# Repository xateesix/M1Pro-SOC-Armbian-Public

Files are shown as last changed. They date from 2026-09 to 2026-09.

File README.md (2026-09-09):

# A3D M1 Pro X1  -  Armbian eMMC Firmware (RK3308BS)

Experimental from-source Armbian firmware for the Artillery M1 Pro S1-SOC control board (Rockchip **RK3308B-S**, board `rk3308bs-evb-m1soc`).

## Project intent

Turn an **otherwise barely usable or unusable** Artillery M1 Pro X1 into a **current mainline Klipper** printer by splitting roles across **new motion hardware** and the **factory S1-SOC board**.

| Role | Hardware | Target software |
|---|---|---|
| **Printer / motion (heavy lifting)** | New **host + CNC Mainboard with new toolhead board** (e.g. [BTT Manta M4P](https://www.biqu.equipment/products/bigtreetech-manta-m4p) + [FYSETC H36](https://www.fysetc.com/products/fysetc-h36-mainboard)) | Mainline **Klipper** on the MCU stack  -  motion, heaters, fans, probe |
| **Display + camera node** | Factory **RK3308 S1-SOC** (this firmware) | **KlipperScreen** on the stock LCD, **Crowsnest** for webcam streaming |

The S1-SOC is **not** the printer MCU. It is an **external companion**  -  UI and camera  -  while the new host + toolhead boards run Klipper for the machine.

The companion image is functional: the **480x272 display works** (Linux DRM/VOP + framebuffer console), **WiFi** is managed by NetworkManager, thermal/touch are working, and the **KlipperScreen + Crowsnest** companion stack is staged for install via KIAUH. Remaining work is on the **motion stack** (Z-stop/probe) and finishing KlipperScreen/Crowsnest configuration.

> ## WARNING  -  READ FIRST
>
> - **Experimental**  -  not supported by Artillery 3D; no warranty.
> - **Void warranty**  -  flashing and hardware mods void manufacturer warranty.
> - **Dangerous voltages**  -  mains AC and 24 V DC. Fire and shock risk.
> - **Extra hardware**  -  USB-C **data** cable, USB-TTL serial adapter (FT232RL), Windows PC with RKDevTool, MASKROM recovery access, plus the **host + toolhead upgrade** for printer control.
> - **You assume all risk**  -  authors are not liable for damage or injury.
>
> Full text: [`docs/WARNING.md`](docs/WARNING.md)

> **Hardware upgrade required for printing:** Motion and Klipper MCU duties need a **3/4-axis host** and **toolhead board** (see below). This S1-SOC image is for the **companion display/camera node**. Repinning JST connectors and high-voltage work can **destroy hardware** or **cause fire**. See [`docs/UPGRADE_PATH.md`](docs/UPGRADE_PATH.md).

## Target architecture (read before flash)

### Motion stack (required for Klipper printing)

| Part | Example |
|---|---|
| **Host** (3 or 4 axis + Klipper MCU) | [BIGTREETECH Manta M4P](https://www.biqu.equipment/products/bigtreetech-manta-m4p) |
| **Toolhead / CNC board** | [FYSETC H36](https://www.fysetc.com/products/fysetc-h36-mainboard) |

This combo does the **heavy lifting**  -  steppers, hotend, bed, probe, and mainline Klipper firmware on the MCU.

**Work in progress:** **Z-stop / Z-probe** still required. Current direction: **Sovol Eddy** in a **custom housing** on the front print head cover. The H36 is chosen for high-temp rating, **3-wire PWM** fan headers, enough GPIO for current and future hardware, and [hopefully] **sideways fit** inside the print head cover.

Details: [`docs/UPGRADE_PATH.md`](docs/UPGRADE_PATH.md).

### 3D printed parts (required for rebuild)

| Part | STEP model |
|---|---|
| Manta M4P mounting bracket | [`models/M4P_M1Pro_Mounting_bracket.step`](models/M4P_M1Pro_Mounting_bracket.step) |
| Power supply relocate bracket | [`models/M1-PowerSupply-Relocate.step`](models/M1-PowerSupply-Relocate.step) |

Print from the STEP files or export STL in your CAD tool. Details: [`docs/UPGRADE_PATH.md`](docs/UPGRADE_PATH.md).

### S1-SOC companion (this repository)

Flash this repo's image on the **factory S1-SOC** to drive:

- **KlipperScreen** on the built-in **480x272** display
- **Crowsnest** for USB webcam streaming to your Klipper stack

The companion talks to your **real Klipper host** (Moonraker on the Manta side) over the network. It does **not** replace the motion boards.

Configuration guide (KlipperScreen  ->  Moonraker IP, Crowsnest on companion, Mainsail/Fluidd webcam URL): [`docs/COMPANION_SETUP.md`](docs/COMPANION_SETUP.md).

Skilled **JST repinning**, **mains / 24 V** awareness, and acceptance of serious risk are required. See [`docs/WARNING.md`](docs/WARNING.md).

## What this is

Experimental **Armbian eMMC firmware** for the **RK3308BS S1-SOC** on the Artillery M1 Pro X1. It replaces the factory Linux image with a lean OS intended as a **KlipperScreen + Crowsnest companion node**, using the stock display and WiFi.

This repository provides the **companion-board firmware and build pipeline**, not the main Klipper MCU firmware for the Manta/H36 stack.

## Media (in this repository)

| Asset | File |
|---|---|
| Hardware overview video (~45 MB) | [`Media/VID_20260615_141308204.mp4`](Media/VID_20260615_141308204.mp4) |
| Boot logo source (BMP) | [`Media/boot-logo-artillery.bmp`](Media/boot-logo-artillery.bmp) |

The custom boot logo is compiled into boot assembly by `tools/build-armbian-bootimg.sh`.

Board overview and control-header pin identification (case light bar, RGB JST, +LED-).
## USB-C data cable (required for flash)

MASKROM flashing and RKDevTool need a **data-capable** USB connection from your PC to the control board USB port.

| Need | Detail |
|---|---|
| **Cable** | Good-quality **USB-C data cable** (USB-C to USB-A or USB-C, matching your PC) |
| **Not sufficient** | Charge-only cables, many cheap phone cables, or long/under-spec cables |
| **Symptom if wrong** | RKDevTool never sees the device, or download fails mid-flash |

Use a cable rated for **data + power**. Short, branded or known data cables are more reliable than generic charge cords. If flash is unstable, try another cable and USB port before changing firmware.

## RKDevTool (required on Windows)

Rockchip firmware flash and the final eMMC **pack** step both use **RKDevTool** on a **Windows PC**. This repository does not bundle RKDevTool.

| Need | Detail |
|---|---|
| **Tool** | RKDevTool (v2.86 or newer recommended)  -  includes `RKDevTool.exe` for flashing and `bin/AFPTool.exe` + `bin/RKImageMaker.exe` for packing |
| **Driver** | Rockchip USB driver via **DriverAssistant** (install before first flash) |
| **Use** | **Upgrade Firmware** tab with a monolithic `.img` (not balenaEtcher / raw `dd`) |
| **USB cable** | Good-quality **USB-C data cable** (see section above) |
| **Recovery** | Board in **MASKROM** (recovery button / maskrom pads + USB) |

**Download and documentation:**

- **Firefly** (ROC-RK3308-CC / RK3308): [Resource downloads (RKDevTool)](https://en.t-firefly.com/doc/download/53.html)  -  [Burning firmware guide](https://wiki.t-firefly.com/en/ROC-RK3308-CC/burning_firmware.html)
- **Radxa** (Rockchip tools): [RKDevTool documentation](https://docs.radxa.com/en/zero/zero3/low-level-dev/rkdevtool)  -  [Windows tools download](https://dl.radxa.com/tools/windows/) (`RKDevTool_Release_v2.86.zip`, `DriverAssistant`)

After installing, run `RKDevTool.exe` as Administrator. Flash steps: [`FLASH_RKDEVTOOL.md`](FLASH_RKDEVTOOL.md).

## USB serial adapter (recommended)

A **USB to TTL serial adapter** lets you see boot logs and log in when WiFi or the display are not set up.

| Need | Detail |
|---|---|
| **Adapter** | FTDI **FT232RL** USB-TTL (3.3 V logic)  -  e.g. [DSD TECH SH-U09C](https://www.amazon.com/DSD-TECH-Adapter-FT232RL-Compatible/dp/B07BBPX8B8) |
| **Level** | Set adapter jumper to **3.3V** (RK3308 UART is 3.3 V TTL) |
| **Wiring** | GND  ->  GND, adapter TXD  ->  board RX, adapter RXD  ->  board TX (UART3 header) |
| **Baud** | **1500000** |
| **Console** | **`ttyS3`** at 1500000 baud (older factory notes mention `ttyFIQ0`) |

Use PuTTY, Tera Term, or `picocom` at **1500000 8N1**. FTDI VCP drivers: [ftdichip.com](https://ftdichip.com/drivers/vcp-drivers/).

Full wiring and terminal notes: [`docs/SERIAL_CONSOLE.md`](docs/SERIAL_CONSOLE.md).

## Download and flash (companion image)

Host-role rule: if build and flash are on different machines, upload the image to the flashing machine first and run flash there. Do not run `upgrade_tool` or `rkdeveloptool` on the build machine.

1. Obtain the monolithic eMMC image `rk3308bs-1.0.0-<release-tag>-emmc.img` (from **GitHub Releases** or your own from-source build).
2. Flash with RKDevTool  ->  **Upgrade Firmware** (or `upgrade_tool uf <image>` on Linux)
3. **Change the default password** on first login

| Account | Username | Default password |
|---|---|---|
| Normal user | `m1prox1` | `m1prox1` |
| Root | `root` | `m1prox1` |

WiFi credentials can be pre-baked at build time (private builds) or configured on first boot with `nmcli` / `nmtui` (NetworkManager).

Release assets: [`docs/RELEASE.md`](docs/RELEASE.md)

## Build from source (GPL / customization)

The firmware is compiled **from source** with Armbian: the board's kernel (with the RK3308BS patch set), rootfs, and the flashable Rockchip eMMC image are all produced by the scripts in this repository.

### Build requirements

| Component | Notes |
|---|---|
| **Linux** (Ubuntu/Debian) | Armbian from-source build + Rockchip packaging (Linux-only tooling) |
| **RKDevTool** or `upgrade_tool` | Flash the resulting image to eMMC |
| **Serial** | USB-TTL adapter (FT232RL, 3.3 V)  -  see section above |

### Steps

```bash
git clone <this-repository-url>
cd <repository-directory>

# Install host build dependencies (first time)
bash tools/install-build-deps.sh

# Build kernel + rootfs from source and pack the flashable eMMC image.
# RELEASE_TAG is mandatory and names the release/output image.
RELEASE_TAG=my-build bash tools/build-from-source-linux.sh
```

Output: `releases/<RELEASE_TAG>/rk3308bs-1.0.0-<RELEASE_TAG>-emmc.img`

To capture a kernel DRM/boot trace for debugging, set `DRM_DEBUG=1` (adds `drm.debug` to the kernel cmdline); production images build with `DRM_DEBUG=0`.

### What the scripts do

| Script | Role |
|---|---|
| `tools/install-build-deps.sh` | Host packages and tools |
| `tools/fetch-build-sources.sh` | Fetch/verify build inputs (factory templates) |
| `tools/build-from-source-linux.sh` | Canonical build entrypoint (kernel+rootfs+pack) |

## Configuration

| File | Purpose |
|---|---|
| `config.env.example` | Defaults  -  safe to commit |
| `config.env.public.example` | Public-facing example values |
| `config.env` | **Local only**  -  never commit (holds real credentials/URLs) |

## Feature status

| Feature | Status |
|---|---|
| S1-SOC companion image (from-source Armbian, kernel 6.18.x) | Working |
| 480x272 parallel-RGB display + framebuffer console + boot logo | Working |
| Serial `ttyS3` @ 1500000 | Working |
| Thermal / TSADC (RK3308BS linear conversion) | Working |
| Goodix touch (GT911, I2C3) | Working |
| WiFi (RTL8189FS) via **NetworkManager** | Working |
| **KlipperScreen** (companion role) | Staged via KIAUH  -  install on device |
| **Crowsnest** (companion role) | Staged via KIAUH  -  install on device |
| Main Klipper MCU (Manta M4P + H36) | **Required separate upgrade**  -  not this image |
| Z-stop / bed probe (motion stack) | **WIP**  -  Sovol Eddy + custom cover mount |
| Case light bar (+LED-) | Pin identified; driver in progress |
| RGB pebbles (WS2812) | Not supported |
| Factory Makerbase UI | Not included |

GPIO map: [`docs/GPIO_AND_HARDWARE.md`](docs/GPIO_AND_HARDWARE.md)
Boot logo: [`docs/BOOT_LOGO.md`](docs/BOOT_LOGO.md)

The image build stages KIAUH, Klipper, Moonraker, KlipperScreen, and Crowsnest source trees under `/opt` during rootfs customization; run `/usr/local/sbin/rk3308bs-setup-companion-stack.sh` on device to install KlipperScreen/Crowsnest via KIAUH.

## Build pipeline

```text
tools/install-build-deps.sh   ->  host build dependencies

RELEASE_TAG=<tag> bash tools/build-from-source-linux.sh
  |-- Armbian compile.sh          (kernel + rootfs from source, patches/ applied)
  |-- build-emmc-release.sh       (stage pack_input from the compiled image)
  |    |-- build-armbian-bootimg.sh  (boot.img: kernel + custom DTB + resource/logo)
  |-- tools/pack-firmware-linux.sh   (afptool/rkImageMaker -> monolithic RKFW image)
```

Output: `releases/<tag>/rk3308bs-1.0.0-<tag>-emmc.img`

## Repository layout

| Path | Description |
|---|---|
| `tools/build-from-source-linux.sh` | Canonical build entrypoint |
| `tools/` | From-source build + Rockchip packaging scripts |
| `patches/` | Kernel and DTS patches (GPL) |
| `config/` | Kernel config fragments |
| `userpatches-chroot/`, `userpatches-kernel/`, `userpatches-boot/` | Armbian build hooks |
| `overlay/` | On-device services + helpers baked into the rootfs |
| `models/` | 3D printed bracket STEP files |
| `docs/` | User documentation |
| `releases/` | Build output (git-ignored) |

## License and disclaimer

GPL-licensed components remain under their respective licenses. Provided as-is for research and self-hosting. Not affiliated with Artillery 3D.

## Changelog

See [`CHANGELOG.md`](CHANGELOG.md).

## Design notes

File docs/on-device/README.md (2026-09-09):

# On-device documentation

Companion firmware for the Artillery M1 Pro X1 S1-SOC (RK3308BS). Additional guides are in this folder.

## Login credentials

Change passwords after first boot.

| Account | Username | Password |
|---|---|---|
| Normal user | `m1prox1` | `m1prox1` |
| Root | `root` | `m1prox1` |

WiFi is **not** pre-configured on the published image.

## Repository media

| Asset | Path on SD/eMMC |
|---|---|
| Hardware overview video | Not on device — see repo [`Media/VID_20260615_141308204.mp4`](https://github.com/xateesix/M1-SOC-Armbian-Build-scripts-public/blob/main/Media/VID_20260615_141308204.mp4) |

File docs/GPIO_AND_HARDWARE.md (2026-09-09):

# GPIO map

Confirmed: case light bar = GPIO2_B3 (gpiochip2 line 11, gpio75), 24 V enable.
RGB NeoPixel: not supported.
Serial console: ttyS3 @ 1500000  -  see docs/SERIAL_CONSOLE.md.

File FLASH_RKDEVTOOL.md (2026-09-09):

# RK3308BS  -  RKDevTool flash guide (Artillery M1 Pro S1-SOC)

## Host role rule (mandatory)

- Build host and flash host are different roles.
- Never run `upgrade_tool` or `rkdeveloptool` on the build host.
- Always upload firmware image from build host to flash host first, then flash on flash host.

Linux flash-host example (SSH alias `flashpc`):

```bash
IMG="rk3308bs-1.0.0-v64-from-source-linux-emmc.img"
SRC="/home/YOUR_USERNAME/scratch/Projects/rk3308bs-workspace/M1-SOC-Armbian-Build/releases/v64-from-source-linux/$IMG"

rsync --partial --append-verify "$SRC" flashpc:~/rk3308bs-firmware/
ssh flashpc "sha256sum ~/rk3308bs-firmware/$IMG"
ssh flashpc "sudo upgrade_tool uf ~/rk3308bs-firmware/$IMG"
```

## Install RKDevTool (not included in this repo)

Use a **Windows PC**. Download RKDevTool and the Rockchip USB driver from vendor tool pages:

| Source | Links |
|-----|----|
| **Firefly** | [RKDevTool download](https://en.t-firefly.com/doc/download/53.html)  -  [ROC-RK3308-CC burning guide](https://wiki.t-firefly.com/en/ROC-RK3308-CC/burning_firmware.html) |
| **Radxa** | [RKDevTool docs](https://docs.radxa.com/en/zero/zero3/low-level-dev/rkdevtool)  -  [Windows tools](https://dl.radxa.com/tools/windows/) |

Recommended: `RKDevTool_Release_v2.86.zip` plus **DriverAssistant**. Install the driver first, then run `RKDevTool.exe` as Administrator.

## USB cable

Use a **good-quality USB-C data cable** between the PC and the board USB port. Charge-only or poor cables often prevent MASKROM detection or cause failed downloads. Try a short, known data cable and a direct motherboard USB port if RKDevTool does not see the device.

## Use Upgrade Firmware + monolithic `.img`

1. Enter **MASKROM** (recovery button / maskrom pads + USB).
2. Open **RKDevTool**.
3. Tab: **Upgrade Firmware** (second tab).
4. **Firmware:** browse to a single monolithic `.img` file.
   - Do **not** load a custom `config.cfg` with separate partition files.
   - Do **not** use **Advanced  ->  Write by address**.
5. Click **Upgrade** / **Run**.
6. Watch the log  -  you **must** see:
   - `Download Boot Success`
   - `Download IDB Success`
   - `Download Firmware Start` with **`Gpt=1`**
   - `Start to download rootfs, offset=0x...` (multi-minute write for large images)
   - `Download Firmware Success` (ret=0, not `ret=1`)
7. Unplug USB, power cycle.

If **Download Boot** fails to start:

- **Advanced**  ->  **Download Loader**  ->  use `MiniLoaderAll.bin` from your partition templates or factory extract
- Immediately repeat step 5 on **Upgrade Firmware** with the **full** `.img`.

---

## Factory reference image

Known-good monolithic package (use for recovery and as packaging reference):

```
KLP_IMG_ARTILLERY_M1_PRO_S1-SOC_20251126_Beta (1)/KLP_IMG_ARTILLERY_M1_PRO_S1-SOC_20251126_Beta.img
```

Unpacked structure matches our repacks:

| Component | Factory | Our repacks |
|---|---|---|
| `boot.bin` (MiniLoader) | 321870 bytes | **identical** |
| `package-file` layout | standard Rockchip | **identical** |
| `parameter.txt` | `TYPE: GPT`, `MAGIC: 0x5041524B` | same format |
| RKImageMaker wrap | `-RK3308` + `-os_type:androidos` | same (`windows-pack-update.ps1`) |

If factory `.img` works on Upgrade but a custom `.img` does not, the problem is **not** the tab  -  check the log for the failure patterns below.

---

## Images

| File | When to use |
|---|---|
| `KLP_IMG_ARTILLERY_..._Beta.img` | **Recovery**  -  known-good factory |
| `SMOKE_v2_repack_only.img` | Validate repack pipeline (factory contents) |
| `rk3308bs-1.0.0-emmc-fixed.img` | Symlink/copy of **latest built** `-vNN.img` (currently **v43** if v45 not built yet) |
| `rk3308bs-1.0.0-emmc-fixed-v43.img` | **Do not use**  -  rootfs baked with `debugfs set_inode_field`  ->  `bogus i_mode` login loop |
| `rk3308bs-1.0.0-emmc-fixed-v45.img` | **Build this next**  -  safe chroot + `/boot/system.cfg` (no v44 image was ever produced) |
| `rk3308bs-1.0.0-emmc-fixed-v42.img` | Last good kernel/display before v43 rootfs patch (no WiFi grow stack) |
| `rk3308bs-1.0.0-emmc-fixed-v14.img` | Old baseline  -  v13 thermal + built-in DRM, no custom WiFi/LCD module load |
| `rk3308bs-1.0.0-emmc-fixed-v13.img` | v11 serial + factory RK3308BS TSADC  -  **do not use** (reboot breaks GPT; LCD blank) |
| `rk3308bs-1.0.0-emmc-fixed-v12.img` | v11 serial + **no thermal emergency reboot** (soc-crit passive workaround) |
| `rk3308bs-1.0.0-emmc-fixed-v11.img` | Factory DTB + ttyS3 serial  -  **still thermal reboot loop on 6.18** |

**Do not use an old `-emmc-fixed.img` from before 2026-06-11**  -  those had a broken `boot.img` header (resource.img in wrong slot  ->  U-Boot PXE/`=>` prompt).

Factory GPT layout (reference):

| # | LBA | Size | Name |
|---|-----|---|---|
| 1 | 0x2000 | 0x1000 | uboot |
| 2 | 0x3000 | 0x1000 | trust |
| 3 | 0x4000 | 0x800 | misc |
| 4 | 0x4800 | 0xa000 | recovery |
| 5 | 0xe800 | 0x4800 | boot (9 MB factory) |
| 6 | 0x13000 | grow | rootfs |

The `-fixed` Armbian image expands boot to **17 MB** (`0x8a00`) and moves rootfs to `0x17200`  -  required for Armbian 6.18 `boot.img`. Upgrade with `Gpt=1` rebuilds GPT from `parameter.txt` inside the package.

---

## Working flash log (June 4  -  factory, Upgrade tab)

```
Download Boot Success
Download IDB Success
Download Firmware Start
  Gpt=1, DirectLBA=1
  Start to download trust, offset=0x3000
  Start to download uboot, offset=0x2000
  Start to download boot,   offset=0xe800
  Start to download rootfs, offset=0x13000   Ã¢â€ Â ~5 GB, several minutes
  Start to download recovery, offset=0x4800
  Start to download misc, offset=0x4000
Download Firmware Success
Reset Device Success
```

---

## Broken flash patterns (June 9  -  do NOT do this)

### Pattern A  -  Write by address / custom config

```
Download parameter at 0x00000000 ...     Ã¢â€ Â destroys GPT at LBA 0
RunProc is ending, ret=1
ERROR: GetParameter_Loader->Check parameter tag failed!
```

Cause: **Advanced  ->  Write by address**, or a `config.cfg` that lists `parameter`, `uboot`, `boot`, etc. as separate files instead of one monolithic `.img`.

### Pattern B  -  partial partition list without Gpt=1

```
Download uboot at 0x00002000 ...
Download trust at 0x00003000 ...
Download boot at 0x0000e800 ...
Download armbian-serial-soc at 0x00000000 ...   Ã¢â€ Â wrong item at LBA 0
RunProc is ending, ret=1
```

Cause: custom config pointing at loose `.img`/`.bin` files (not the monolithic update package).

### Pattern C  -  flash too fast

Flash finishes in under ~30 seconds on a multi-GB image  ->  only loader/IDB written, not full firmware.

---

## What each symptom means

| Symptom | Cause |
|---|-----|
| Instant MASKROM, no button | IDB / boot sectors corrupt (bad or partial flash) |
| No partition table in MASKROM | GPT never created (`Gpt=1` path not run) |
| U-Boot `=>` + pxelinux / PXE | Boot partition empty, **truncated boot.img**, or **broken boot.img header** |
| `boot partition is not enough to save image!` | Use `rk3308bs-1.0.0-emmc-fixed.img` (17 MB boot slot) |

---

## Serial

After successful recovered v67 flash: **UART3 @ 1500000**, console **`ttyS3`** (older factory notes mention `ttyFIQ0`).

Verify:

```bash
cat /etc/rk3308bs-release
```

---

## PXE / `=>` prompt after Armbian flash (troubleshooting)

That output means **U-Boot never started the kernel**  -  it is not a rootfs issue yet.

### If you see MASKROM loader output (`Code check error -1`, `tag:LOADER error`)

**Cause:** `rk3308bs-1.0.0-emmc-fixed-v4.img` patched `uboot.img` and broke Rockchip's hash check. **Do not use v4.**

**Recovery:**

1. MASKROM  ->  flash **factory** `KLP_IMG_ARTILLERY_..._Beta.img` (full ~5 GB)
2. Then flash **`rk3308bs-1.0.0-emmc-fixed-v11.img`** (or `rk3308bs-1.0.0-emmc-fixed.img`  -  same as v11)

### `Invalid DTB hash !` / `No valid DTB, ret=-22`

**Cause:** Custom `rk-kernel.dtb` was injected into `resource.img` without updating the RSCE SHA1 entry. U-Boot (`CONFIG_ROCKCHIP_DTB_VERIFY`) rejects the DTB before loading the kernel.

**Fix:** Use **`rk3308bs-1.0.0-emmc-fixed-v6.img`** or newer. v6 rebuilds `boot.img` with correct DTB hash + size in `resource.img`.

Serial symptom (v5 and earlier):

```
DTB: rk-kernel.dtb
HASH(c): error
Invalid DTB hash !
Failed to load android image
```

After v6+ you should see `HASH(c): OK`. If boot then **loops** with overlap/`overwritten` errors, flash **v7** (see below).

### Boot loop: kernel overlaps FDT (`Sysmem Error` / `image overwritten`)

**Cause:** Armbian 6.18 decompresses to ~40 MiB starting at `0x00280000`, but factory U-Boot places the FDT at `fdt_addr_r=0x01f00000` (~31 MiB). The kernel clobbers the device tree  ->  U-Boot resets  ->  loop.

Serial symptom (v6):

```
HASH(c): OK
Booting LZ4 kernel at 0x02480000(Uncompress to 0x00280000) with fdt at 0x01f00000
Sysmem Error: "UNCOMP_KERNEL" ... overlap with existence "FDT" (0x01f00000 ...)
ERROR: new format image overwritten - must RESET the board to recover
```

**Fix:** Flash **`rk3308bs-1.0.0-emmc-fixed-v7.img`** (v6 boot + patched `uboot.img` memory map **with corrected LOADER hash**). v4 had the same env patch but a broken hash (`Code check error -1`); v7 adds the `hash_by_crypto` value the MiniLoader expects.

Expected after v7:

```
HASH(c): OK
... with fdt at 0x05000000
Starting kernel ...
```

### Kernel panic: `Unable to mount root fs on unknown-block(0,0)`

**Cause:** Rockchip U-Boot passes **`/chosen/bootargs` from the DTB** to Linux, not the `boot.img` header cmdline. Custom DTB only had `console=`  -  no `root=PARTUUID=...`  -  so the kernel panics even though boot succeeds.

Serial symptom (v7):

```
Kernel command line: ... console=ttyS3,1500000n8
VFS: Cannot open root device "" or unknown-block(0,0)
Kernel panic - not syncing: VFS: Unable to mount root fs
```

Partition list shows rootfs at **`mmcblk0p6`** / **`614e0000-0000-4b53-8000-1d28000054a9`**  -  the data is there; the kernel just wasn't told where to mount.

**Fix:** Flash **`rk3308bs-1.0.0-emmc-fixed-v8.img`** (v7 + DTB `bootargs` with `root=PARTUUID=614e0000-0000-4b53-8000-1d28000054a9 rootfstype=ext4 rw rootwait`).

Expected after v8:

```
Kernel command line: ... root=PARTUUID=614e0000-0000-4b53-8000-1d28000054a9 rootfstype=ext4 rw rootwait
EXT4-fs (mmcblk0p6): mounted filesystem with ordered data mode
```

### Boot loop after Ã¢â‚¬Å“Welcome to ArmbianÃ¢â‚¬Â (`Temperature too high`)

**Cause:** Custom DTB (v8) is missing the factory **`/otp`** node used to calibrate the TSADC. The sensor reads too hot  ->  instant critical trip  ->  `reboot: HARDWARE PROTECTION shutdown`  ->  loop. v8 otherwise works (root mounts, systemd starts).

Serial symptom:

```
Welcome to Armbian-unofficial 26.08.0-trunk bookworm!
thermal thermal_zone1: soc-thermal: critical temperature reached
reboot: HARDWARE PROTECTION shutdown (Temperature too high)
```

**Fix (serial + root):** v8/v11 bootargs and ttyS3. **Thermal loop:** use **v13** (proper TSADC) or **v12** workaround (passive soc-crit).

**Do not** run manual `saveenv` unless v7 still fails  -  v7+ bakes the memory layout into default env.

### No serial output / boot loop (v9 - v10)

**Cause:** Factory DTB **disables** `serial@ff0d0000` and routes UART3 through **fiq-debugger** (`console=ttyFIQ0`). That works on factory kernel **5.10**, but **Armbian 6.18 does not ship fiq-debugger**  -  so neither `ttyFIQ0` nor `ttyS3` works after `earlycon`, and the serial port goes silent while the board keeps resetting (thermal/display activity may still occur).

v8 had serial because the **custom DTB** enabled `serial@ff0d0000` + `console=ttyS3` (but lacked factory OTP  ->  thermal loop).

**Fix:** Flash **`rk3308bs-1.0.0-emmc-fixed-v11.img`**  -  factory DTB (OTP/thermal) with **fiq-debugger disabled**, **`serial@ff0d0000=okay`**, **`console=ttyS3,1500000n8`**. Same UART header @ **1500000**.

**Note:** v11 serial works, but Armbian **6.18** still hits `soc-thermal: critical temperature reached` ~1 s after boot (factory `/otp` in DTB is not enough for mainline TSADC trim). See **v12** below.

Expected after **v13** (preferred) or **v12** (workaround):

```
Kernel command line: ... console=ttyS3,1500000n8 root=PARTUUID=614e0000-0000-4b53-8000-1d28000054a9 ...
Welcome to Armbian-unofficial ...
rk3308bs login:
```

On **v13**, also check idle temperature is sane (not instant critical trip):

```
cat /sys/class/thermal/thermal_zone0/temp
# expect ~30000 - 50000 (millidegrees C) at room temp
```

### Thermal reboot ~1 s after boot (v8, v11)

**Cause:** TSADC reads too hot without mainline OTP trim  ->  instant **critical** trip  ->  `reboot: HARDWARE PROTECTION shutdown (Temperature too high)`  ->  looks like a very fast boot loop. Serial **does** work on v11 (full dmesg through USB/MMC init, then reboot at ~1 s).

```
thermal_sys: No trip points found for tsadc id=1
thermal thermal_zone0: soc-thermal: critical temperature reached
reboot: HARDWARE PROTECTION shutdown (Temperature too high)
```

v8 reached `Welcome to Armbian` first (custom DTB, no factory OTP) then the same thermal shutdown. v9 - v11 kept factory OTP in DTB but **6.18** still reboots early.

**Fix:** Flash **`rk3308bs-1.0.0-emmc-fixed-v13.img`**  -  factory DTB + ttyS3 + kernel **`rockchip,rk3308bs-tsadc`** linear conversion (see **`THERMAL_RK3308BS.md`**).

**Workaround (no kernel rebuild):** **`rk3308bs-1.0.0-emmc-fixed-v12.img`**  -  same as v11 but **`soc-crit` downgraded to passive** so Linux does not emergency-reboot (readings still wrong; trips disabled).

### Armbian 6.18 kernel + factory U-Boot memory layout (manual fallback)

Factory `uboot.img` only leaves ~25 MiB for a decompressed kernel (`kernel_addr_r=0x00680000`, `fdt_addr_r=0x01f00000`). Armbian 6.18 is larger  ->  `boot_android` fails  ->  PXE/`=>`.

**Manual fallback only** (v5/v6 at `=>` with `bootdelay` > 0). v7 should not need this:

```
setenv fdt_addr_r 0x05000000
setenv kernel_addr_r 0x02080000
setenv kernel_addr_c 0x08000000
saveenv
reset
```

If `saveenv` succeeds, the next boot should load the kernel (watch for Linux messages, not PXE).

### Checklist (normal flash path)

1. **Factory recovery first**  -  flash `KLP_IMG_ARTILLERY_..._Beta.img` (full ~5 GB, `rootfs @ 0x13000`). Confirm the board boots factory again.

2. **Flash the fixed Armbian image**  -  **`rk3308bs-1.0.0-emmc-fixed-v14.img`** (v7 uboot + v14 boot/kernel + reboot-safe rootfs).  
   **Never** use `-v4.img` (patched uboot **without** hash fix  -  bricks at loader).  
   **Avoid v13** after first boot  -  Armbian resize corrupts fixed GPT (see below).

3. **Read the RKDevTool log**  -  both lines are required:
   ```
   Start to download boot, offset=0xe800, size=14630912
   Start to download rootfs, offset=0x17200, size=1647312896
   ```
   (v12 used `size=18040832` for boot  -  still valid if you flash v12. Boot must fit the 17 MiB partition.)
   If `rootfs` is missing (log shows `total=33613312` only), the rootfs partition is empty  -  see **Option B** in the main guide (Advanced  ->  write `rootfs.img` at **`0x17200`**).

4. **At the U-Boot `=>` prompt** (optional diagnosis):
   ```
   mmc dev 0
   mmc part
   ```
   Boot partition must be **~17 MiB** (not 9 MiB). If it still shows 9 MiB, parameter/GPT did not update  -  redo step 1, then step 2.

### Why this happens

| Cause | What happened |
|----|---|
| `Invalid DTB hash` | Custom DTB in `resource.img` without RSCE SHA1 update (fixed in v6+) |
| Boot loop / `image overwritten` | Kernel decompress overlaps FDT at `0x01f00000` (fixed in v7 uboot env + hash) |
| Kernel panic `unknown-block(0,0)` | DTB missing `root=PARTUUID=...` in `/chosen/bootargs` (fixed in v8+) |
| Thermal reboot (~1 s or after banner) | TSADC uncalibrated on Armbian 6.18 (fix: v13+ RK3308BS linear TSADC; workaround: v12 passive soc-crit) |
| Reboot hang / kernel panic after first boot | `armbian-resize-filesystem` expanded rootfs GPT on eMMC  -  U-Boot shows empty part 5 name and wrong size; fixed in **v14** (`/root/.no_rootfs_resize`) |
| Blank LCD after Linux | DRM built as modules but not installed (v13); fixed in **v14** (built-in `CONFIG_DRM_ROCKCHIP=y`) |
| Silent serial / boot loop on v9 - v10 | Factory DTB disables UART3 unless fiq-debugger works (Armbian 6.18 has none)  -  fixed in v11 |
| `Code check error -1` | Patched uboot without LOADER hash update (v4; fixed in v7) |
| Old `-emmc-fixed.img` | `boot.img` had `resource.img` in ramdisk slot instead of second slot  ->  U-Boot rejects it |
| v43 `Authentication failure` / `bogus i_mode (644)` | Rootfs corrupted by `patch-rootfs-v17-debugfs.sh`. **Full flash v45** after building (not update over grown eMMC) |
| No v44 firmware | v44 script existed but **never built**  -  use `tools/build-release-v45-rootfs-only.sh` |
| Partial flash (`total=33613312`) | Boot written but rootfs skipped; GPT may not match |
| 9 MiB boot slot + 17 MiB boot.img | U-Boot reads truncated image  ->  same PXE symptom |

## Erase vs partition table (important)

**RKDevTool "Erase Flash" does NOT remove the GPT.** It wipes partition *data* (zeros flash blocks). The partition table layout often persists or is immediately **rebuilt** on the next flash.

| Action | GPT effect | Data effect |
|-----|---|---|
| **Erase Flash** (Advanced) | GPT usually **unchanged** | Partition contents zeroed |
| **Upgrade Firmware** + monolithic `.img` | **`Gpt=1` rebuilds GPT** from `parameter.txt` inside the image | Writes trust, uboot, boot, rootfs, etc. |
| **Factory full image** flash | Full GPT + all partitions | Clean baseline |

**Only Upgrade Firmware** (main tab) with a complete `rk3308bs-*.img` rebuilds GPT correctly *and* writes partition data. Erase alone is never enough.

### What your 12:30 flash did (Putty + RKDevTool log)

```
total=30342656          boot-only (~1 sec)  -  wrong image (v46 grow-only)
Gpt=1                   GPT rebuilt  ->  rootfs *name* appeared (grow size 0xe78ddf)
(no rootfs line)        rootfs *data* never written  ->  empty/corrupt rootfs
```

Putty then shows `LoadTrustBL error:-3` / `No find trust.img!`  -  trust area invalid after erase + incomplete flash.

### Correct recovery sequence

1. **Do not rely on Erase** to fix GPT  -  it will not clear the table.
2. MASKROM  ->  **Upgrade Firmware** (main tab, NOT Advanced write-by-address).
3. Select **`rk3308bs-1.0.0-emmc-fixed-v47.img`** (~1.68 GB).
4. **Before clicking Run**, confirm image file size ~1.6 GB on disk.
5. Log **must** show:
   ```
   total=1677655552
   Start to download rootfs,offset=0x17200,size=1647312896
   ```
   (~47 - 48 seconds for rootfs). If `total=30342656`, STOP  -  wrong image or wrong mode.
6. After success, GPT should show part 6 **rootfs** @ `0x17200` (size may display as grow `0xe78ddf`  -  OK if rootfs data was written).

### Putty logs

Save session logs to `C:\Workspaces\Putty-log\` for boot/flash verification.

## Boot hang at "clk: Disabling unused clocks"

**Symptom:** Serial stops after `clk: Disabling unused clocks`. No login, no panic.

**Cause:** eMMC (`mmc0`) never creates `mmcblk0`. Kernel blocks on `rootwait` for `PARTUUID=614e0000-...`.

Compare to factory dmesg (works):
```
mmc0 HS200 -> Waiting for root -> Successfully tuned phase -> mmcblk0 -> EXT4 mount
```

v48 PuTTY log (hangs):
```
mmc2: SD card detected (mmcblk2)   <- SD slot occupied
mmc0 HS200
(no "Successfully tuned phase")
(no mmcblk0)
clk: Disabling unused clocks
```

**Fix:** Remove the microSD card from the printer before boot. Factory images were tested with an empty SD slot. SD probe on `mmc@ff480000` (mmc2) can prevent eMMC tuning from completing.

**Verify after removing SD:**
- `dwmmc_rockchip ff490000.mmc: Successfully tuned phase to ...`
- `mmcblk0: mmc0:0001 ...`
- `EXT4-fs (mmcblk0p6): mounted filesystem`
- autologin on ttyFIQ0

SD slot can be used after boot for extra storage; avoid booting with a card inserted until we add a DT defer fix.

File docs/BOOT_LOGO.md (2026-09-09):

# Boot logo

The build pipeline now treats the custom 480x272 logo as part of boot assembly.

Flow:

1. [Media/boot-logo-artillery.bmp](../Media/boot-logo-artillery.bmp) is the source bitmap.
2. `tools/build-armbian-bootimg.sh` packs `resource.img` from the factory template.
3. `tools/patch-resource-logos.py` patches both `logo.bmp` and `logo_kernel.bmp` slots.

If the logo file is missing, the assembler keeps the template logo and prints a warning.

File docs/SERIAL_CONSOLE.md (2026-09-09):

# Serial console (UART debug)

Required for boot logs, login, and troubleshooting when display or network are not enough.

## Adapter

Use a **USB to TTL serial adapter** with a genuine **FTDI FT232RL** chip (stable drivers on Windows).

Example (tested): [DSD TECH SH-U09C on Amazon](https://www.amazon.com/DSD-TECH-Adapter-FT232RL-Compatible/dp/B07BBPX8B8) (model SH-U09C, FT232RL, includes Dupont cable).

| Requirement | Detail |
|---|---|
| Chip | FTDI FT232RL (or FT232RNL) recommended over CP2102/CH340 |
| Logic level | **3.3 V TTL**  -  set the adapter VCC jumper to **3.3V** (not 5V) |
| Pins used | **GND**, **TXD** (adapter  ->  board RX), **RXD** (adapter  ->  board TX) |
| Cable | Female-to-female Dupont jumpers (often included with the adapter) |

Do **not** connect adapter **VCC** to the board unless you intentionally need to power something; GND + TX + RX are enough for console.

## Board settings

| Setting | Value |
|---|---|
| Header | UART3 on the S1-SOC control board |
| Baud rate | **1500000** (not 115200) |
| Linux console | **`ttyS3`** at 1500000 baud (older factory notes mention `ttyFIQ0`) |
| Data | 8N1, no flow control |

## PC terminal

| OS | Examples |
|----|---|
| Windows | PuTTY, Tera Term, or `putty -serial COMx -sercfg 1500000` |
| Linux / WSL | `picocom -b 1500000 /dev/ttyUSB0` or `minicom` |

Select the COM port assigned to the FTDI adapter. If the port does not appear, install drivers from [FTDI](https://ftdichip.com/drivers/vcp-drivers/).

## Safety

Printer mains and 24 V may be present on the board. Prefer debugging with **USB/network disconnected from the printer** when probing headers, or work only when qualified.

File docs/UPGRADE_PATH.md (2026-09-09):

# Host + toolhead upgrade and S1-SOC companion role

## Project goal

Make an Artillery M1 Pro X1 that is **barely usable or unusable** on the factory stack into a **current mainline Klipper** printer  -  not by running everything on the old RK3308 board, but with a **split architecture**.

| Role | Hardware | Software |
|---|---|---|
| **Motion / Klipper MCU** | New **host + CNC toolhead** | Mainline **Klipper** (heavy lifting) |
| **Display + camera** | Factory **S1-SOC** (RK3308) | **KlipperScreen**, **Crowsnest** |

The S1-SOC is an **external companion node**  -  stock LCD and network for UI and webcam  -  while the new boards control the printer.

**Status:** The S1-SOC companion image is functional (display, WiFi, thermal, touch working; KlipperScreen/Crowsnest staged for install). Remaining work is on the **motion stack**: Z-stop/probe is unfinished.

## Motion stack (required)

| Role | Example hardware |
|---|---|
| **Main host** (3 or 4 axis + Klipper MCU) | [BIGTREETECH Manta M4P](https://www.biqu.equipment/products/bigtreetech-manta-m4p) |
| **Toolhead / CNC board** | [FYSETC H36](https://www.fysetc.com/products/fysetc-h36-mainboard) |

This pair runs **Klipper** for motion, heaters, fans, and (once complete) bed probing. The S1-SOC does **not** replace this stack.

## 3D printed parts (required for rebuild)

The motion-stack upgrade needs two **printed brackets** in the repository `models/` directory:

| Part | STEP file | Purpose |
|---|---|---|
| **Manta M4P mounting bracket** | [`M4P_M1Pro_Mounting_bracket.step`](../models/M4P_M1Pro_Mounting_bracket.step) | Mount the BTT Manta M4P inside the M1 Pro chassis |
| **Power supply relocate bracket** | [`M1-PowerSupply-Relocate.step`](../models/M1-PowerSupply-Relocate.step) | Relocate the factory PSU to clear space for the new host |

Print from the STEP source or export STL from your CAD tool before assembly.

## Why FYSETC H36 (example toolhead)

| Factor | Notes |
|---|---|
| **Temperature rating** | High-temp tolerance for enclosed / hot chamber use |
| **Fan headers** | Multiple **3-wire PWM** fan outputs (not 4-wire RGB) |
| **Expansion** | Enough headers for required and future hardware |
| **Mechanical fit** | Target **sideways** install inside the front print head cover (validation ongoing) |

## Z-stop / probing (work in progress)

Mainline Klipper on the motion stack still needs a reliable **Z reference**.

- **Sovol Eddy** probe
- **Custom housing** on the **front print head cover**
- Wired through the **Manta M4P + H36** stack (not the S1-SOC companion)

## What this repository is for

**Companion firmware** for the factory S1-SOC board:

- Lean **Armbian** on eMMC
- Built-in **480x272** display for **KlipperScreen** (target)
- Network services for **Crowsnest** (target)
- Talks to the **real Klipper host** (Moonraker on the Manta) over WiFi/LAN

It is **not** the Klipper MCU image for the Manta or H36.

Setup guide: [`COMPANION_SETUP.md`](COMPANION_SETUP.md)  -  KlipperScreen + Crowsnest on the S1-SOC, Moonraker on the Manta.

## If you modify harnesses

Expect **delicate JST repinning**, mains and 24 V exposure, and serious failure modes. See [`WARNING.md`](WARNING.md).

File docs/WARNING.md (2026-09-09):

# EXPERIMENTAL FIRMWARE  -  READ BEFORE USE

Experimental firmware for the Artillery M1 Pro S1-SOC (RK3308BS). **Not supported** by Artillery 3D.

## Architecture (read this)

| Board | Role |
|---|---|
| **Host + toolhead** (e.g. Manta M4P + FYSETC H36) | Main **Klipper MCU**  -  motion, heaters, probe |
| **S1-SOC** (this firmware) | **Companion only**  -  **KlipperScreen** + **Crowsnest** |

You need **both** paths for the full project: upgrade the motion stack **and** flash this companion image on the S1-SOC.

Details: [`UPGRADE_PATH.md`](UPGRADE_PATH.md)

## Skills and risks

- **JST repinning**, high voltage (**mains AC**, **24 V**), fire and equipment damage risk.
- Incorrect work can destroy boards or **cause fire** (including structural fire risk).
- **Void warranty.** **You assume all risk.**

## Hardware

USB-C data cable, USB-TTL serial (FT232RL), Windows PC with RKDevTool. See [`README.md`](README.md).
- **3D printed brackets** for Manta M4P mount and PSU relocate - see [`models/`](../models/) and [`UPGRADE_PATH.md`](UPGRADE_PATH.md).

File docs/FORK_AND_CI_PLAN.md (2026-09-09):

# Fork upstream sources and GitHub CI plan

Companion firmware for Artillery M1 Pro X1 S1-SOC (RK3308BS). This document plans owning the full source stack: forks, patch queues, and automated rebuild on GitHub.

## Current pipeline (today)

```text
[Linux build host]  RELEASE_TAG=<tag> tools/build-from-source-linux.sh
        |  Armbian compile.sh: kernel (patches/*.patch) + board config + userpatches
        |  -> compiled Armbian image (kernel + rootfs) from source
        v
   build-emmc-release.sh -> build-armbian-bootimg.sh (boot.img: kernel + custom DTB + logo)
        |
   tools/pack-firmware-linux.sh (afptool / rkImageMaker, Linux-only)
        v
   releases/<tag>/rk3308bs-1.0.0-<tag>-emmc.img
```

The current line **recompiles the kernel and rootfs from source** (Armbian) and
packs the monolithic Rockchip image with Linux-only tooling. There is no Windows
pack step and no prebuilt "build-artifacts tarball" repatch model anymore.

## Target architecture

```text
                    +------------------+
                    |  This repo       |
                    |  M1-SOC-Armbian  |
                    |  - board DTS     |
                    |  - patches/      |
                    |  - userpatches   |
                    |  - tools/       |
                    |  - GitHub Actions|
                    +--------+---------+
                             |
         +-------------------+-------------------+
         |                   |                   |
         v                   v                   v
 +---------------+   +---------------+   +------------------+
 | fork:         |   | fork:         |   | fork (optional): |
 | armbian/build |   | linux stable  |   | rockchip rkbin   |
 |               |   | v6.18.y       |   | MiniLoader, etc. |
 +---------------+   +---------------+   +------------------+
```

### Repos to fork (under `xateesix` or org)

| Fork | Upstream | Role |
|---|---|---|
| `M1-SOC-armbian-build` | `github.com/armbian/build` | Image compile framework, `compile.sh`, board hooks |
| `M1-SOC-linux` | `github.com/gregkh/linux` branch `linux-6.18.y` | Kernel + our `patches/*.patch` as commits or quilt series |
| `M1-SOC-Armbian-Build` (existing private) | — | Board integration, from-source pack pipeline, docs, release scripts |
| `M1-SOC-Armbian-Build-scripts-public` (current public) | export of sanitized tree + Releases |

Optional: vendor `factory_fresh` partition templates in this repo or a small `M1-SOC-rk3308-factory` submodule (Rockchip loader binaries are redistributable per vendor terms; document provenance).

## Patch strategy

| Layer | Location today | Fork strategy |
|---|---|---|
| Kernel DTS + drivers | `patches/0001-0009`, `dts/` | Apply as git commits on `M1-SOC-linux` or export quilt series synced by CI |
| Armbian board | `rk3308bs-evb.conf`, `userpatches-*` | Pin in `M1-SOC-armbian-build` fork or copy into `userpatches/` on each sync |
| Boot DTB (display, lights) | `tools/patch-dtb-*.py`, `build-armbian-bootimg.sh` | Stay in integration repo; inputs = kernel Image + factory resource |
| Rootfs companion | `userpatches-chroot/*.sh`, `overlay/` | Stay in integration repo; public `m1prox1` / no WiFi |

**Rule:** forks hold **upstream-shaped** changes; integration repo holds **product** scripts (from-source pack, companion docs, release).

## GitHub Actions (proposed)

### Workflow 1: `sync-upstream.yml` (weekly + manual)

- Checkout forks with `actions/checkout`
- Subtree or scripted merge from upstream tags (`armbian` release branch, `linux-6.18.y`)
- Re-apply patch queue (fail PR if conflicts)
- Open auto-PR `upstream-sync-YYYY-MM-DD` for human review

### Workflow 2: `build-artifacts.yml` (self-hosted Linux runner)

**Runner:** same class as `your-host` Ubuntu (label `rk3308-builder`) with cached `armbian-build` tree.

```yaml
on:
  push:
    branches: [main]
  workflow_dispatch:

jobs:
  armbian-image:
    runs-on: [self-hosted, rk3308-builder]
    steps:
      - checkout integration repo
      - source config.env.public.example
      - RELEASE_TAG=ci-${{ github.sha }} bash tools/build-from-source-linux.sh
      - upload-artifact: rk3308bs-1.0.0-<tag>-emmc.img (or split if >2GB)
```

### Workflow 3: `release.yml` (on tag `v*`)

- Attach the `.img` to a GitHub Release (external mirror if >2 GB)
- Run `tools/push-to-public.sh` for the source-only public snapshot
- **Gate:** manual approval / only after a test flash job passes

### Secrets

| Secret | Use |
|---|-----|
| `BUILD_SSH_KEY` | self-hosted runner registration |
| `DISCORD_WEBHOOK_URL` | optional build notify (private repo only) |

No WiFi or user passwords in CI — use `config.env.public.example` only.

## Migration phases

### Phase 1 — Now (local)

- [x] `tools/build-from-source-linux.sh` — from-source kernel+rootfs build and Linux-only eMMC pack
- [x] Allow-listed public export (`tools/push-to-public.sh` + `.public-export-allow`)
- [ ] Flash-test image before any Release upload
- [ ] Commit integration scripts + `docs/FORK_AND_CI_PLAN.md`

### Phase 2 — Forks

1. Fork `armbian/build` and `linux` on GitHub
2. Push kernel patches as commits; tag `m1pro-v6.18.1-r1`
3. Document `BRANCH` / `KERNELBRANCH` pins in `config.env.example`
4. Set `FETCH_ARMBIAN_SOURCE=1` / `FETCH_KERNEL_SOURCE=1` to clone forks instead of upstream

### Phase 3 — Self-hosted CI

1. Register Ubuntu builder + Windows pack runner
2. Implement `build-artifacts.yml` + artifact cache
3. Implement companion pack job with RKDevTool v2.86 path

### Phase 4 — Upstream sync automation

1. `sync-upstream.yml` with conflict PRs
2. Optional: Dependabot-style weekly kernel stable tag check

## File size / Release constraints

- Monolithic `.img` is ~6.4 GB — **exceeds GitHub single-asset 2 GB limit**
- Options: self-hosted release mirror, split download, Git LFS + billing, or OCI bucket (S3/R2) with Release linking URL only

Plan: CI uploads tarball to release; `.img` hosted on external mirror until GitHub Large File Storage or chunking is configured.

## Local commands (maintainer)

```bash
# Full from-source build (kernel + rootfs) and eMMC pack
RELEASE_TAG=<tag> bash tools/build-from-source-linux.sh

# Public export (no firmware in git; allow-listed squashed snapshot)
bash tools/push-to-public.sh
```

## Open decisions

1. **Org vs personal forks** — single `xateesix` org for all forks?
2. **Kernel line** — stay on 6.18.y vs track Armbian `current` branch?
3. **Image hosting** — where to put 6 GB `.img` for public users?
4. **Test gate** — manual flash checklist vs automated hardware test runner?

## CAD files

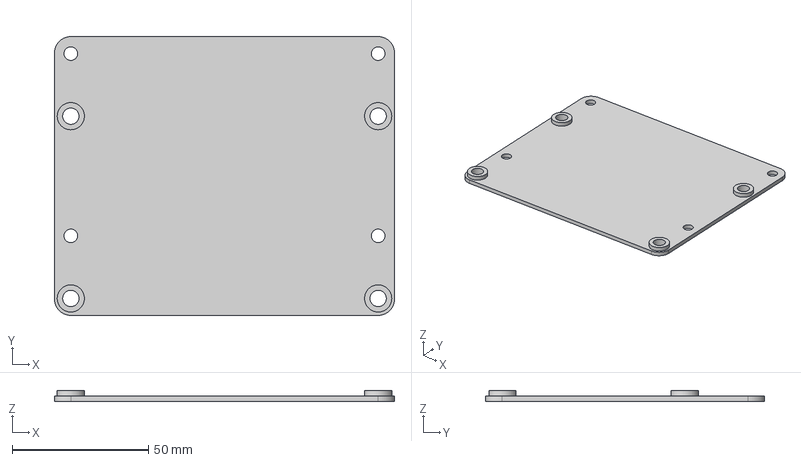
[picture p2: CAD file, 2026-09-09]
models/M1-PowerSupply-Relocate.step
125.0 x 102.5 x 4.00 mm

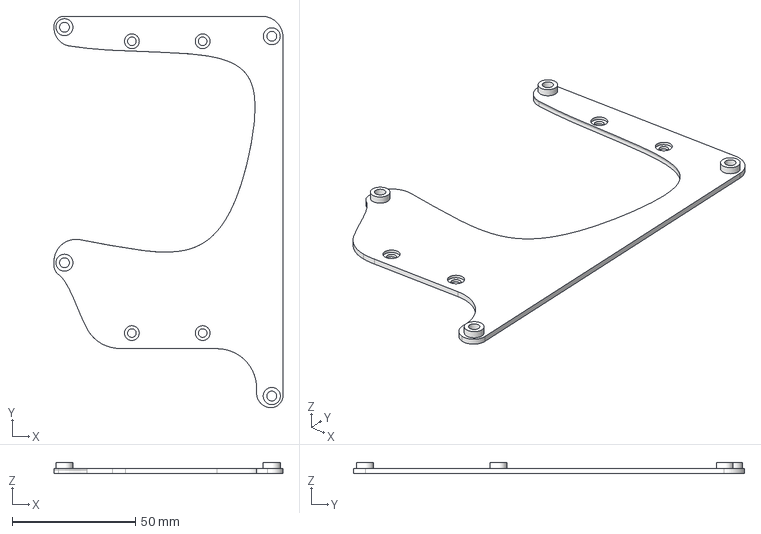
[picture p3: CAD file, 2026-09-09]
models/M4P_M1Pro_Mounting_bracket.step
93.0 x 159.0 x 4.50 mm

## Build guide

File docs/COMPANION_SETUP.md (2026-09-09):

# Companion setup: KlipperScreen + Crowsnest on the S1-SOC

The factory **S1-SOC** (this Armbian image) is a **secondary host**. It does **not** run Klipper for printer motion. It runs **KlipperScreen** and **Crowsnest** and talks to the **main Klipper host** (e.g. BTT Manta M4P + FYSETC H36) over the network.

Decouple UI and camera from the main instance: Moonraker stays on the motion stack; the companion only serves display and webcam streams.

**Status:** the image build now stages the companion stack at compile time. The build pulls KIAUH, Klipper, Moonraker, KlipperScreen, and Crowsnest source trees directly into `/opt` (e.g. `/opt/kiauh`, `/opt/klipper`), then seeds a starter `KlipperScreen.conf` and a companion-stack manifest under `/etc/rk3308bs`.

## Prerequisites

| Item | Where |
|---|---|
| Main Klipper + **Moonraker** running | Motion host (Manta M4P, etc.) |
| Companion image flashed | S1-SOC eMMC (`rk3308bs-1.0.0-<release-tag>-emmc.img`) |
| Same LAN | Both hosts reachable (WiFi or Ethernet) |
| Webcam (for Crowsnest) | USB camera on **companion** or routed as your build requires |

Note the **IP addresses**:

- `<MAIN_HOST_IP>`  -  Manta / Moonraker (example `192.168.1.50`)
- `<COMPANION_IP>`  -  S1-SOC (example `192.168.1.51`)

## Step 1: KlipperScreen on the companion (S1-SOC)

KlipperScreen only needs the **Moonraker API**. Do **not** install a Klipper MCU stack on the S1-SOC for printer control.

The simplest path is the on-device helper, which wires the remote host, fixes `/opt` ownership, refreshes the apt index (so KIAUH's package installs don't hit stale-pool 404s), and launches KIAUH:

```bash
/usr/local/sbin/rk3308bs-setup-companion-stack.sh
```

In KIAUH, choose **Install -> KlipperScreen** (and **Crowsnest**). To re-open KIAUH later, just run `kiauh` (the wrapper refreshes apt automatically).

Manual details, if you prefer to wire it yourself:

1. Review `/etc/rk3308bs/companion-stack.env` on the companion.
2. Install or finish wiring the stack using the staged source trees directly under `/opt` (e.g. `/opt/kiauh`, `/opt/klipper`).
3. Edit KlipperScreen config (seeded into `/etc/skel/.config/KlipperScreen.conf` during build, and commonly copied into `~/.config/KlipperScreen.conf` after first boot).
4. Point at the **main** Moonraker instance:

```ini
[printer M1ProX1]
moonraker_host: <MAIN_HOST_IP>
moonraker_port: 7125
```

5. Restart KlipperScreen. The **480x272** panel on the S1-SOC should show telemetry and controls for the printer on the motion host.

Multi-printer / remote Moonraker patterns: [KlipperScreen documentation](https://github.com/KlipperScreen/KlipperScreen) and guides on controlling multiple printers via Moonraker host settings.

## Step 2: Crowsnest on the companion (S1-SOC)

Crowsnest is an independent streaming server. It can run on the second host with **no Klipper** on that host.

References: [Running crowsnest on an external device (Mainsail Crew #2252)](https://github.com/orgs/mainsail-crew/discussions/2252)

1. Use the staged `crowsnest` source tree directly under `/opt/crowsnest` or install via KIAUH if you prefer its workflow.
2. Edit `/etc/crowsnest.conf` on the **companion**  -  camera device, resolution, and stream port (commonly **8080**).
3. Start or restart Crowsnest and confirm the stream is live:

```text
http://<COMPANION_IP>:8080/webcam/?action=stream
```

## Step 3: Point Mainsail / Fluidd at the companion stream

Your **web UI runs on the main host** (or your usual browser target). Add the companion camera as an **external** webcam URL.

1. Open **Mainsail** or **Fluidd** (connected to Moonraker on `<MAIN_HOST_IP>`).
2. **Settings**  ->  **Webcams**  ->  add camera.
3. Stream URL:

```text
http://<COMPANION_IP>:8080/webcam/?action=stream
```

4. Save and refresh the dashboard.

The motion host serves Klipper/Moonraker; the companion serves video. Same pattern as multi-camera setups with a separate streaming device.

## Summary

```text
  [ Manta M4P + H36 ]          LAN          [ S1-SOC companion ]
  Klipper + Moonraker  <----------------->  KlipperScreen  ->  Moonraker API
       :7125                                  Crowsnest     ->  :8080 stream
       Mainsail/Fluidd  ----browser---->  webcam URL = COMPANION_IP:8080
```

## Related docs

- [`UPGRADE_PATH.md`](UPGRADE_PATH.md)  -  motion stack (Manta + H36)
- [`README.md`](README.md)  -  project overview
- [`SERIAL_CONSOLE.md`](SERIAL_CONSOLE.md)  -  debug without display/WiFi

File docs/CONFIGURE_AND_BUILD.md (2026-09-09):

# Configure and build

Companion image for the S1-SOC (KlipperScreen + Crowsnest). Motion Klipper runs on a separate host (Manta/H36).

The image is compiled **from source** with Armbian: the board kernel (with the RK3308BS patch set in `patches/`), the rootfs, and the flashable Rockchip eMMC image are all produced by the build. The build also bakes in the custom boot logo and stages companion software source trees (KIAUH, Klipper, Moonraker, KlipperScreen, Crowsnest) under `/opt` (e.g. `/opt/kiauh`, `/opt/klipper`).

```bash
# First time: install host build dependencies
bash tools/install-build-deps.sh

# Build from source and pack the eMMC image. RELEASE_TAG is mandatory.
RELEASE_TAG=my-build bash tools/build-from-source-linux.sh
```

Output: `releases/<RELEASE_TAG>/rk3308bs-1.0.0-<RELEASE_TAG>-emmc.img`

Optional build variables:

| Variable | Default | Effect |
|---|---|---|
| `RELEASE_TAG` | (required) | Names the release directory and output image |
| `DRM_DEBUG` | `0` | `1` adds `drm.debug` to the kernel cmdline for display tracing |
| `EXTRA_BOOTARGS` | (empty) | Extra kernel cmdline tokens appended to the DTB bootargs |

After flash, see [`COMPANION_SETUP.md`](COMPANION_SETUP.md) for Moonraker/Crowsnest wiring.

See [`README.md`](../README.md) and [`FLASH_RKDEVTOOL.md`](../FLASH_RKDEVTOOL.md).

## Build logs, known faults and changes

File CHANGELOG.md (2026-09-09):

# Changelog

## Unreleased (2026-09)
- **Display working**: fixed the RK3308 DRM/VOP bring-up. Restored the
  pre-enable-before-CRTC modeset order (patch 0012) and guarded the NULL
  optional panel regulator that Oops'd at the first modeset (patch 0013).
  The 480x272 panel now lights up with a Linux framebuffer console.
- **VOP resets**: inject CRU resets (axi/ahb/dclk) into the VOP node so
  `rockchip-drm` binds on kernel 6.18.x.
- **Networking**: migrated WiFi from netplan/systemd-networkd to
  **NetworkManager** (required by KlipperScreen); WiFi credentials seeded
  as an NM keyfile connection profile.
- **Companion stack**: fix `/opt` ownership for KIAUH and refresh the apt
  index before KIAUH installs so KlipperScreen/Crowsnest dependencies no
  longer fail on stale-pool 404s.
- **Build tooling**: single canonical from-source build entrypoint
  (`tools/build-from-source-linux.sh`); mandatory `RELEASE_TAG`;
  `EXTRA_BOOTARGS`/`DRM_DEBUG` diagnostic hook.
- **Board rename**: `rk3308bs-evb-m1soc` promoted to a real, in-tree
  kernel DTS build artifact.

## v0.64.1 (2026-06-16)
- Fix m1prox1 home ownership; remove legacy xateesix home/group
- Disable systemd ANSI on framebuffer boot console (tty0)
- Plain-text MOTD branding
- Credential bake: subuid/subgid, home chown, WiFi scrub

## v0.64.1 (2026-06-15)
- Public release: interactive configure.sh, documentation, GPIO hardware map
- Case light bar pin GPIO2_B3 confirmed; RGB deferred
- eMMC pipeline build-release-v64.sh

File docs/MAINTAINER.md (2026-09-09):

# Maintainer notes (private workflow)

## Dual repository workflow

| Remote | Purpose |
|---|---|
| **Private** (`origin`) | Full development tree: discovery/debug history, local configs, factory data |
| **Public** | Sanitized, allow-listed snapshot for community use |

```bash
git push origin main              # private: all work
bash tools/push-to-public.sh      # public: allow-listed squashed snapshot
```

Set `PUBLIC_REPO_URL` in `config.env`.

## Public export model

`tools/push-to-public.sh` publishes the public repo as a **fresh, squashed
snapshot** (a single orphan commit), not a copy of private history. This is
deliberate:

- **Allow-list**, not deny-list: only paths matched by `.public-export-allow`
  are published. Anything new (discovery scripts, factory data, audit dumps,
  reverse-engineering notes, session logs) is dropped by default.
- **No shared history**: because the public repo is a single commit, private
  commit messages and any pre-sanitization diffs (which contained real
  credentials) can never reach the public remote via `git log`.
- **Sanitization pass**: as defense-in-depth, the kept files are still scrubbed
  of known credential/host/path patterns before commit.

To change what is published, edit `.public-export-allow` and re-run the export.

## Public export safety

- Treat `config.env`, logs, serial captures, and release binaries as private-only unless explicitly sanitized.
- Never add secret-bearing paths to `.public-export-allow`; the real `config.env` is excluded (only `config.env.example` templates are published).
- Keep the public repository limited to sanitized source, templates, and approved release artifacts.
- Assume the workspace is unstable and may close at any time; preserve durable notes in tracked files, not live session state.

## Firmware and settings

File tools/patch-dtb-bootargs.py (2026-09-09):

#!/usr/bin/env python3
"""Set /chosen/bootargs on a DTB (Rockchip U-Boot uses this, not boot.img cmdline)."""
from __future__ import annotations

import argparse
import shutil
import struct
import subprocess
import sys
from pathlib import Path


def patch_with_fdtput(
    dtb: Path,
    bootargs: str,
    out: Path,
    stdout_path: str = "",
) -> None:
    fdtput = shutil.which("fdtput")
    if not fdtput:
        raise FileNotFoundError("fdtput not found (install device-tree-compiler)")

    tmp = out
    if out.resolve() != dtb.resolve():
        tmp.write_bytes(dtb.read_bytes())

    subprocess.check_call(
        [fdtput, "-t", "s", str(tmp), "/chosen", "bootargs", bootargs],
    )
    if stdout_path:
        subprocess.check_call(
            [fdtput, "-t", "s", str(tmp), "/chosen", "stdout-path", stdout_path],
        )


def compile_dts_source(dts: Path, out: Path, kernel_root: Path | None = None) -> None:
    """Compile a DTS source to a compact DTB so the final blob stays under the Rockchip resource slot."""
    cpp = shutil.which("cpp")
    dtc = shutil.which("dtc")
    if not cpp or not dtc:
        raise FileNotFoundError("cpp/dtc not found (install device-tree-compiler)")

    if kernel_root is None:
        candidates = [
            Path("/home/YOUR_USERNAME/scratch/Projects/rk3308bs-workspace/M1-SOC-Armbian-Build/cache/sources/linux-kernel-worktree"),
            Path("/home/YOUR_USERNAME/scratch/Projects/rk3308bs-workspace/M1-SOC-Armbian-Build/cache/sources/linux-kernel-worktree"),
        ]
        found = None
        for cand in candidates:
            if cand.exists():
                for child in sorted(cand.iterdir()):
                    if (child / "arch/arm64/boot/dts/rockchip/rk3308.dtsi").exists():
                        found = child
                        break
                if found is not None:
                    break
        if found is None:
            raise FileNotFoundError(
                "Could not locate linux-kernel-worktree with arch/arm64/boot/dts/rockchip/rk3308.dtsi; "
                "pass --kernel-root or compile from a binary DTB."
            )
        kernel_root = found

    pre = out.with_suffix(".pre.dts")
    try:
        with pre.open("wb") as pre_fh:
            subprocess.check_call(
                [
                    cpp,
                    "-nostdinc",
                    "-undef",
                    "-D__DTS__",
                    "-x",
                    "assembler-with-cpp",
                    "-I",
                    str(kernel_root / "arch/arm64/boot/dts"),
                    "-I",
                    str(kernel_root / "arch/arm64/boot/dts/rockchip"),
                    "-I",
                    str(kernel_root / "include"),
                    str(dts),
                ],
                stdout=pre_fh,
            )
        subprocess.check_call(
            [
                dtc,
                "-I",
                "dts",
                "-O",
                "dtb",
                "-o",
                str(out),
                "-i",
                str(kernel_root / "arch/arm64/boot/dts"),
                "-i",
                str(kernel_root / "arch/arm64/boot/dts/rockchip"),
                "-i",
                str(kernel_root / "include"),
                str(pre),
            ],
        )
    finally:
        if pre.exists():
            pre.unlink()


def extract_factory_dtb(resource: Path) -> bytes:
    data = resource.read_bytes()
    old_size, off = _find_fdt_slot(data)
    return data[off : off + struct.unpack(">I", data[off + 4 : off + 8])[0]]


def _remove_dts_subnode(text: str, name: str) -> str:
    """Remove a child node block like 'display-timings { ... };' from DTS source."""
    needle = f"{name} {{"
    start = text.find(needle)
    if start < 0:
        return text
    line_start = text.rfind("\n", 0, start) + 1
    depth = 0
    i = text.find("{", start)
    while i < len(text):
        ch = text[i]
        if ch == "{":
            depth += 1
        elif ch == "}":
            depth -= 1
            if depth == 0:
                end = i + 1
                while end < len(text) and text[end] in " \t":
                    end += 1
                if end < len(text) and text[end] == ";":
                    end += 1
                if end < len(text) and text[end] == "\n":
                    end += 1
                return text[:line_start] + text[end:]
        i += 1
    return text


def patch_rk3308_panel_dpi(dtb: Path) -> None:
    """Use upstream panel-dpi + panel-timing instead of legacy simple-panel binding."""
    dtc = shutil.which("dtc")
    if not dtc:
        raise FileNotFoundError("dtc not found (install device-tree-compiler)")

    dts = dtb.with_suffix(".panel.dts")
    subprocess.check_call([dtc, "-I", "dtb", "-O", "dts", "-o", str(dts), str(dtb)], stderr=subprocess.DEVNULL)
    text = dts.read_text()
    if 'compatible = "simple-panel"' in text:
        text = text.replace('compatible = "simple-panel"', 'compatible = "panel-dpi"', 1)
    text = _remove_dts_subnode(text, "display-timings")
    timing_block = (
        "\t\tpanel-timing {\n"
        "\t\t\tclock-frequency = <0x895440>;\n"
        "\t\t\thactive = <0x1e0>;\n"
        "\t\t\tvactive = <0x110>;\n"
        "\t\t\thback-porch = <0x2b>;\n"
        "\t\t\thfront-porch = <0x08>;\n"
        "\t\t\tvback-porch = <0x0c>;\n"
        "\t\t\tvfront-porch = <0x08>;\n"
        "\t\t\thsync-len = <0x04>;\n"
        "\t\t\tvsync-len = <0x04>;\n"
        "\t\t\thsync-active = <0x01>;\n"
        "\t\t\tvsync-active = <0x01>;\n"
        "\t\t\tde-active = <0x00>;\n"
        "\t\t\tpixelclk-active = <0x01>;\n"
        "\t\t};\n"
    )
    if "panel-timing {" not in text:
        panel_idx = text.find("panel {")
        if panel_idx < 0:
            raise RuntimeError("panel node not found in decompiled DTS")
        port_idx = text.find("port {", panel_idx)
        if port_idx < 0:
            raise RuntimeError("panel port node not found in decompiled DTS")
        line_start = text.rfind("\n", panel_idx, port_idx) + 1
        text = text[:line_start] + timing_block + text[line_start:]
    dts.write_text(text)
    subprocess.check_call(
        [dtc, "-I", "dts", "-O", "dtb", "-o", str(dtb), str(dts), "-Wno-unit_address_vs_reg"],
    )
    dts.unlink(missing_ok=True)
    print(
        "  panel compatible=panel-dpi panel-timing=480x272@9MHz "
        "(removed display-timings; bus-format unchanged on /panel)"
    )


def patch_goodix_factory_defaults(dtb: Path) -> None:
    fdtget = shutil.which("fdtget")
    fdtput = shutil.which("fdtput")
    if not fdtget or not fdtput:
        raise FileNotFoundError("fdtget/fdtput not found")

    candidates = [
        "/i2c@ff070000/goodix_ts@5d",
        "/i2c@ff070000/touchscreen@5d",
    ]
    node = None
    for cand in candidates:
        rc = subprocess.call(
            [fdtget, str(dtb), cand, "compatible"],
            stdout=subprocess.DEVNULL,
            stderr=subprocess.DEVNULL,
        )
        if rc == 0:
            node = cand
            break

    if node is None:
        print("  goodix node not found, skipping factory defaults")
        return

    subprocess.check_call([fdtput, "-t", "i", str(dtb), node, "touchscreen-size-x", "800"])
    subprocess.check_call([fdtput, "-t", "i", str(dtb), node, "touchscreen-size-y", "480"])

    for prop, value in (("max-x", "800"), ("max-y", "480")):
        rc = subprocess.call(
            [fdtget, str(dtb), node, prop],
            stdout=subprocess.DEVNULL,
            stderr=subprocess.DEVNULL,
        )
        if rc == 0:
            subprocess.check_call([fdtput, "-t", "i", str(dtb), node, prop, value])

    print("  goodix: size=800x480 (factory GPIO flags preserved)")


def _find_goodix_node(dtb: Path) -> str | None:
    fdtget = shutil.which("fdtget")
    if not fdtget:
        raise FileNotFoundError("fdtget not found")
    for cand in ("/i2c@ff070000/goodix_ts@5d", "/i2c@ff070000/touchscreen@5d"):
        rc = subprocess.call(
            [fdtget, str(dtb), cand, "compatible"],
            stdout=subprocess.DEVNULL,
            stderr=subprocess.DEVNULL,
        )
        if rc == 0:
            return cand
    return None


def patch_goodix_calibration(dtb: Path, min_x: int, size_x: int,
                             min_y: int, size_y: int) -> None:
    """Declare the physically-reachable GT911 coordinate window via the kernel
    touchscreen core's device-tree calibration properties.

    The GT911 digitizer glass is larger than the 480x272 panel, so with the
    stock 480x272 config only part of the reported coordinate range lands on
    the visible panel (measured: X 0..438, Y 34..179). Rather than rescaling
    the chip config (which cannot apply a Y offset without a driver hack), we
    tell the input core the real min/size on each axis. libinput then maps
    [min .. min+size-1] linearly onto the full screen, giving edge-to-edge
    touch with correct offset. See drivers/input/touchscreen.c
    touchscreen_parse_properties() -- it sets ABS min=touchscreen-min-* and
    max=touchscreen-size-*-1, which libinput uses to normalize coordinates.
    """
    fdtput = shutil.which("fdtput")
    if not fdtput:
        raise FileNotFoundError("fdtput not found")
    node = _find_goodix_node(dtb)
    if node is None:
        print("  goodix node not found, skipping calibration")
        return
    for prop, value in (
        ("touchscreen-min-x", min_x),
        ("touchscreen-size-x", size_x),
        ("touchscreen-min-y", min_y),
        ("touchscreen-size-y", size_y),
    ):
        subprocess.check_call([fdtput, "-t", "i", str(dtb), node, prop, str(value)])
    print(f"  goodix: calibration min-x={min_x} size-x={size_x} "
          f"min-y={min_y} size-y={size_y} (reachable window -> full screen)")


def _find_fdt_slot(data: bytes) -> tuple[int, int]:
    magic = b"\xd0\x0d\xfe\xed"
    candidates: list[tuple[int, int]] = []
    offset = 0
    while True:
        idx = data.find(magic, offset)
        if idx < 0:
            break
        if idx + 8 <= len(data):
            totalsize = struct.unpack(">I", data[idx + 4 : idx + 8])[0]
            if 64 <= totalsize <= len(data) - idx:
                candidates.append((totalsize, idx))
        offset = idx + 4
    if not candidates:
        raise SystemExit("No FDT magic found")
    totalsize, off = max(candidates, key=lambda x: x[0])
    slot_end = off + totalsize
    while slot_end < len(data) and data[slot_end] == 0 and (slot_end - off) <= 65536:
        slot_end += 1
    return slot_end - off, off


def main() -> int:
    ap = argparse.ArgumentParser(description=__doc__)
    ap.add_argument("--dtb", type=Path, help="Input DTB (not needed with --from-factory-resource or --dts)")
    ap.add_argument("--dts", type=Path, help="Optional source .dts to compile first so the DTB stays compact enough for the resource slot")
    ap.add_argument("--kernel-root", type=Path, help="Optional linux-kernel-worktree root used to resolve include files when compiling --dts")
    ap.add_argument("--output", required=True, type=Path)
    ap.add_argument(
        "--console",
        default="",
        help="console= value (default: ttyFIQ0 with --from-factory-resource, else ttyS3,1500000n8)",
    )
    ap.add_argument(
        "--root-uuid",
        default="614e0000-0000-4b53-8000-1d28000054a9",
        help="rootfs GPT PARTUUID from parameter.txt uuid:rootfs=",
    )
    ap.add_argument("--bootargs", default="", help="Full bootargs override")
    ap.add_argument(
        "--extra-bootargs",
        default="",
        help="Extra tokens appended to the generated (or overridden) bootargs, "
        "e.g. debug flags like 'drm.debug=0x1f ignore_loglevel'",
    )
    ap.add_argument(
        "--stdout-path",
        default=None,
        help="/chosen/stdout-path (default: skip for factory DTB, else serial3:1500000n8)",
    )
    ap.add_argument(
        "--from-factory-resource",
        type=Path,
        help="Extract rk-kernel.dtb from factory resource.img instead of --dtb",
    )
    ap.add_argument(
        "--armbian-serial",
        action="store_true",
        help="Legacy: disable fiq-debugger and use ttyS3 (do not use on RK3308BS  -  console is ttyFIQ0)",
    )
    ap.add_argument(
        "--disable-thermal-critical",
        action="store_true",
        help="Downgrade soc-crit trip to passive at 120C",
    )
    ap.add_argument(
        "--rk3308bs-tsadc",
        action="store_true",
        help="Set tsadc compatible to rockchip,rk3308bs-tsadc (needs kernel patch 0002)",
    )
    ap.add_argument(
        "--disable-tsadc",
        action="store_true",
        help="Disable tsadc node in DTB as an emergency workaround for early thermal resets",
    )
    ap.add_argument(
        "--rk3308-vop-resets",
        action="store_true",
        help="Add CRU resets (axi/ahb/dclk) to vop@ff2e0000 (rockchipdrm bind needs ahb reset)",
    )
    ap.add_argument(
        "--rk3308-panel-dpi",
        action="store_true",
        help="Panel: panel-dpi + panel-timing (480x272@9MHz) for Linux 6.18 DRM",
    )
    ap.add_argument(
        "--goodix-factory-defaults",
        action="store_true",
        help="Force Goodix IRQ active-low and touchscreen size to 800x480",
    )
    ap.add_argument(
        "--goodix-calibration",
        metavar="MINX,SIZEX,MINY,SIZEY",
        default="",
        help="Declare reachable GT911 window via touchscreen-min/size props so "
             "libinput stretches it to full screen (e.g. 0,439,34,181)",
    )
    args = ap.parse_args()

    src = args.dtb
    if args.dts:
        src = args.output.with_suffix(".compiled.dtb")
        compile_dts_source(args.dts, src, kernel_root=args.kernel_root)
        print(f"Compiled DTS ({args.dts}) -> DTB ({len(src.read_bytes())} bytes)")
    if args.from_factory_resource:
        blob = extract_factory_dtb(args.from_factory_resource)
        src = args.output.with_suffix(".extracted.dtb")
        src.write_bytes(blob)
        print(f"Extracted factory DTB ({len(blob)} bytes) from {args.from_factory_resource}")
    elif not src:
        ap.error("Provide --dtb, --dts, or --from-factory-resource")

    console = args.console
    if not console:
        if args.armbian_serial or not args.from_factory_resource:
            console = "ttyS3,1500000n8"
        else:
            console = "ttyFIQ0"

    stdout_path = args.stdout_path
    if stdout_path is None:
        stdout_path = "serial3:1500000n8" if args.armbian_serial or not args.from_factory_resource else ""

    if args.bootargs:
        bootargs = args.bootargs
    else:
        bootargs = (
            f"earlycon=uart8250,mmio32,0xff0d0000 console={console} "
            f"root=PARTUUID={args.root_uuid} rootfstype=ext4 rw rootwait"
        )

    if args.extra_bootargs.strip():
        bootargs = f"{bootargs} {args.extra_bootargs.strip()}"

    try:
        patch_with_fdtput(
            src,
            bootargs,
            args.output,
            stdout_path=stdout_path,
        )
        if args.armbian_serial:
            fdtput = shutil.which("fdtput")
            if not fdtput:
                raise FileNotFoundError("fdtput not found")
            subprocess.check_call(
                [fdtput, "-t", "s", str(args.output), "/fiq-debugger", "status", "disabled"],
            )
            subprocess.check_call(
                [fdtput, "-t", "s", str(args.output), "/serial@ff0d0000", "status", "okay"],
            )
            print("  fiq-debugger=disabled serial@ff0d0000=okay (Armbian ttyS3 console)")
        if args.disable_thermal_critical:
            fdtput = shutil.which("fdtput")
            if not fdtput:
                raise FileNotFoundError("fdtput not found")
            crit = "/thermal-zones/soc-thermal/trips/soc-crit"
            subprocess.check_call(
                [fdtput, "-t", "s", str(args.output), crit, "type", "passive"],
            )
            subprocess.check_call(
                [fdtput, "-t", "i", str(args.output), crit, "temperature", "120000"],
            )
            print("  soc-crit=passive @ 120C")
        if args.rk3308bs_tsadc:
            fdtput = shutil.which("fdtput")
            if not fdtput:
                raise FileNotFoundError("fdtput not found")
            subprocess.check_call(
                [
                    fdtput,
                    "-t",
                    "s",
                    str(args.output),
                    "/tsadc@ff1f0000",
                    "compatible",
                    "rockchip,rk3308bs-tsadc",
                ],
            )
            print("  tsadc@ff1f0000 compatible=rockchip,rk3308bs-tsadc")
        if args.disable_tsadc:
            fdtput = shutil.which("fdtput")
            if not fdtput:
                raise FileNotFoundError("fdtput not found")
            subprocess.check_call(
                [fdtput, "-t", "s", str(args.output), "/tsadc@ff1f0000", "status", "disabled"],
            )
            print("  tsadc@ff1f0000 status=disabled")
        if args.rk3308_vop_resets:
            fdtput = shutil.which("fdtput")
            if not fdtput:
                raise FileNotFoundError("fdtput not found")
            # SRST_VOP_A/H/D = 38/39/40; cru phandle = 2 in factory DTB
            subprocess.check_call(
                [
                    fdtput,
                    "-t",
                    "i",
                    str(args.output),
                    "/vop@ff2e0000",
                    "resets",
                    "2",
                    "38",
                    "2",
                    "39",
                    "2",
                    "40",
                ],
            )
            subprocess.check_call(
                [
                    fdtput,
                    "-t",
                    "s",
                    str(args.output),
                    "/vop@ff2e0000",
                    "reset-names",
                    "axi",
                    "ahb",
                    "dclk",
                ],
            )
            print("  vop@ff2e0000 resets=SRST_VOP_A/H/D reset-names=axi,ahb,dclk")
        if args.rk3308_panel_dpi:
            patch_rk3308_panel_dpi(args.output)
        if args.goodix_factory_defaults:
            patch_goodix_factory_defaults(args.output)
        if args.goodix_calibration.strip():
            parts = [p.strip() for p in args.goodix_calibration.split(",")]
            if len(parts) != 4:
                print("--goodix-calibration needs MINX,SIZEX,MINY,SIZEY", file=sys.stderr)
                return 1
            cx0, cxs, cy0, cys = (int(p) for p in parts)
            patch_goodix_calibration(args.output, cx0, cxs, cy0, cys)
    except FileNotFoundError as exc:
        print(exc, file=sys.stderr)
        return 1

    print(f"Wrote {args.output}")
    print(f"  bootargs={bootargs!r}")
    return 0


if __name__ == "__main__":
    sys.exit(main())

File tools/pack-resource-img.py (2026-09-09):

#!/usr/bin/env python3
"""Replace the main DTB inside a Rockchip resource.img (preserve bundle size)."""
from __future__ import annotations

import argparse
import hashlib
import struct
import sys
from pathlib import Path


def find_largest_fdt(data: bytes) -> tuple[int, int]:
    magic = b"\xd0\x0d\xfe\xed"
    candidates: list[tuple[int, int]] = []
    offset = 0
    while True:
        idx = data.find(magic, offset)
        if idx < 0:
            break
        if idx + 8 <= len(data):
            totalsize = struct.unpack(">I", data[idx + 4 : idx + 8])[0]
            if 64 <= totalsize <= len(data) - idx:
                candidates.append((totalsize, idx))
        offset = idx + 4
    if not candidates:
        raise SystemExit("No FDT magic found in resource.img template")
    totalsize, off = max(candidates, key=lambda x: x[0])
    # Rockchip resource.img leaves zero padding after the FDT blob; allow reuse.
    slot_end = off + totalsize
    while slot_end < len(data) and data[slot_end] == 0 and (slot_end - off) <= 65536:
        slot_end += 1
    return slot_end - off, off


def find_entr_entry(data: bytes, name: str) -> int:
    needle = b"ENTR" + name.encode("ascii") + b"\x00"
    idx = data.find(needle)
    if idx < 0:
        raise SystemExit(f"ENTR entry {name!r} not found in resource.img")
    return idx


def update_entr_hash_and_size(out: bytearray, entr_off: int, new_dtb: bytes) -> None:
    """Rockchip U-Boot verifies SHA1 of rk-kernel.dtb (CONFIG_ROCKCHIP_DTB_VERIFY)."""
    hash_off = entr_off + 0xE0
    size_off = entr_off + 0x108
    if hash_off + 20 > len(out) or size_off + 4 > len(out):
        raise SystemExit(f"ENTR metadata out of range @ 0x{entr_off:x}")

    sha1 = hashlib.sha1(new_dtb).digest()
    out[hash_off : hash_off + 20] = sha1
    struct.pack_into("<I", out, size_off, len(new_dtb))


def patch_dtb(template: bytes, new_dtb: bytes) -> bytes:
    old_size, off = find_largest_fdt(template)
    if len(new_dtb) > old_size:
        raise SystemExit(
            f"New DTB ({len(new_dtb)} bytes) exceeds slot in template ({old_size} bytes @ 0x{off:x}). "
            "Rebuild DTS or use a smaller overlay."
        )

    out = bytearray(template)
    out[off : off + len(new_dtb)] = new_dtb
    # Update FDT totalsize field in place
    struct.pack_into(">I", out, off + 4, len(new_dtb))
    # Zero pad remainder of old slot
    if len(new_dtb) < old_size:
        out[off + len(new_dtb) : off + old_size] = b"\x00" * (old_size - len(new_dtb))

    update_entr_hash_and_size(out, find_entr_entry(bytes(out), "rk-kernel.dtb"), new_dtb)
    return bytes(out)


def main() -> int:
    ap = argparse.ArgumentParser(description=__doc__)
    ap.add_argument("--template", required=True, type=Path, help="Factory resource.img template")
    ap.add_argument("--dtb", required=True, type=Path, help="New board DTB")
    ap.add_argument("--output", required=True, type=Path)
    args = ap.parse_args()

    template = args.template.read_bytes()
    new_dtb = args.dtb.read_bytes()
    if new_dtb[:4] != b"\xd0\x0d\xfe\xed":
        raise SystemExit(f"Not a DTB: {args.dtb}")

    out = patch_dtb(template, new_dtb)
    args.output.write_bytes(out)
    old_size, off = find_largest_fdt(template)
    print(f"Wrote {args.output} ({len(out)} bytes)")
    print(f"  replaced FDT @ 0x{off:x}: {old_size} -> {len(new_dtb)} bytes")
    return 0


if __name__ == "__main__":
    sys.exit(main())
